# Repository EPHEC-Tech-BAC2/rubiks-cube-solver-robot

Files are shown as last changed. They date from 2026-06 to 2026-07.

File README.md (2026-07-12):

# Rubik's Cube Solver Robot

Projet réalisé à l'EPHEC-Tech (A2073 — Robotique Part 2, classe 2AU, 2025-2026), en équipe de trois : **EL YAZAMI Yassine**, **MAZID Mohamed**, **ELHAMAYDA Amer**.

## Le projet

Conception et réalisation d'un robot autonome capable de scanner, résoudre et exécuter physiquement la solution d'un Rubik's Cube, sans intervention humaine. Le système combine trois domaines : électronique, mécanique et développement logiciel.

Le robot scanne les 6 faces du cube via une caméra, calcule la solution optimale avec l'algorithme de Kociemba, puis l'exécute grâce à 4 bras motorisés pilotés par un Raspberry Pi Pico W.

## Partie électronique

PCB sur mesure conçu sous **EasyEDA** et fabriqué via **JLCPCB** (81,15 × 88,14 mm, 21 composants, 2 couches de cuivre, 141 pastilles traversantes, 6 vias).

| Composant | Référence | Rôle |
|---|---|---|
| Raspberry Pi Pico W | RP2040 | Microcontrôleur principal (firmware MicroPython) |
| Module Bluetooth | HC-05 | Communication sans fil PC ↔ Pico (UART, 38400 bauds) |
| Lecteur RFID | MFRC522 | Identification par badge, autorisation d'accès |
| Écran OLED | SSD1306 0,96" | Affichage état du robot, face scannée, progression |
| LED RGB | TJ-L5FCMXHTCSLCRGB | Indicateur visuel (rouge = bloqué, vert = prêt, bleu = actif) |
| Servomoteurs | MG90S x8 | 4 rotations + 4 pinces, PWM 50 Hz |
| Bouton | TS665CJ | Appui court = toggle pinces, appui long = scan auto |

L'alimentation des servomoteurs est séparée de celle du Pico pour éviter les chutes de tension lors des mouvements simultanés.

## Partie mécanique

Structure organisée autour d'une base centrale (découpée au laser) sur laquelle se fixent 4 bras en croix (Front, Back, Left, Right), chacun composé d'un servomoteur de rotation et d'un servomoteur de pince. Toutes les pièces ont été modélisées sous **Fusion 360** et imprimées en PLA :

- Platine principale (support servomoteur de rotation)
- Colonne verticale (support servomoteur de pince)
- Pince en U (saisie des faces du cube)
- Support de caméra
- Engrenage et cadre structural en U

Plusieurs itérations d'impression ont été nécessaires pour ajuster les tolérances dimensionnelles et obtenir des mouvements précis. Chaque bras dispose de son propre calibrage (ROT_CENTER, GRIP_HOLD) pour compenser les asymétries mécaniques.

## Partie programmation

Architecture logicielle en deux blocs communiquant en Bluetooth :

- **Firmware Pico (MicroPython)** : gestion des 8 servomoteurs, lecture RFID, affichage OLED, machine à états (IDLE/MOVING/SCAN)
- **Application PC (Python 3, Tkinter)** : capture caméra, détection des couleurs (OpenCV/HSV), interface graphique, résolution Kociemba

Protocole de communication maison : `START:TAG:PAYLOAD:END\n`, avec des tags dédiés (MOVE, GRAB/RELEASE, START_SCAN, PROG, DONE, AUTH...).

**Détection des couleurs** : analyse HSV par patch, vote majoritaire sur 7 captures par face pour plus de robustesse (l'orange est testé avant le rouge, leurs plages HSV étant adjacentes).

**Résolution** : algorithme de Kociemba embarqué localement (hors ligne), garantissant une solution en 20 mouvements maximum.

## Difficultés rencontrées

- Précision des angles de servomoteurs → calibrage individuel par bras
- Confusion orange/rouge en détection HSV → ordre de test + fallback par distance circulaire
- Instabilité de la détection couleur → vote majoritaire sur 7 captures
- Bruit d'initialisation du HC-05 → parsing basé sur la recherche du pattern `START:`
- Chutes de tension lors des mouvements simultanés → alimentation séparée + séquencement
- Tolérances d'impression 3D → révisions dimensionnelles successives

## Contenu du dépôt

- `Partie électronique/` : fichier PCB et export Gerber
- `Partie mécanique/` : fichiers STL de toutes les pièces imprimées + fichier DWG du support du robot
- `Partie programmation/` : firmware MicroPython (dossier `PICO/`) et application de contrôle (dossier `PC/`)
- `Présentation/` : support PowerPoint de la présentation finale
- `Rapport/` : rapport complet du projet (DOCX + PDF)

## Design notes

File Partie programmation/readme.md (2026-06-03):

# A2073 - Robotique part2 - 2025-2026
## Robot Solveur Rubik's Cube 3x3x3

**Groupe : B2**
- NOM Prénom (Matricule)
- EL YAZAMI Yassine (HE305212)
- ELHAMAYDA Amer (HE305196)
- MAZID Mohamed (HE305165)

**Objectifs :**  
Initialisation du projet et mise en place des bases logicielles et matérielles (Pico W, Bluetooth, librairies Python)  

**État actuel :**  
- Structure du projet créée 
- Librairies MicroPython (ssd1306, servo, mfrc522)  
- Dépendances Python ajoutées (numpy, opencv-python, pyserial, kociemba)  
- Début de la conception mécanique et du PCB  
- Test pour vérifier la communication Bluetooth entre le Pico et le PC avant l’intégration dans le projet
- Lancer l'interface et se connecter au Pico
- Les boutons Attraper/Relâcher envoient au Pico, le RFID s'affiche, le chrono tourne.
- Camera dans l'interface + cube mis a jour apres chaque capture
- Capturer 6 faces, resoudre, envoyer au pico, voir la progression en direct
- Utilisation de l'écran OLED pour afficher l’état et les messages du robot.
- Lecture de badges RFID pour l’identification.
- Mise en place de l’application Tkinter avec l’affichage du cube, la caméra live, le Bluetooth, le RFID, le chronomètre et le journal d’événements.
- Ajout du flux de capture des 6 faces du cube, la détection des couleurs, l’actualisation de l’état du cube à l’écran et la construction de la chaîne de résolution Kociemba.
- Passer le lancement par un écran d’accueil.
- Afficher le retour caméra directement dans l’interface.
- Construire la chaîne Kociemba après le scan complet.
- Calculer et afficher la solution du cube.
- Envoyer automatiquement les mouvements au robot.
- Mettre à jour l’état du cube pendant l’exécution des mouvements.
- Gérer la progression de la résolution en live.
- version finale de la communication BT, interface PC, OLED et RFID.

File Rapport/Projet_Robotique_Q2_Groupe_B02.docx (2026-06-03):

EPHEC — HAUTE ECOLE | TECH

Classe : 2AU — Année académique 2025-2026

A2073 - Robotique (Part 2)

RAPPORT FINAL

Rubik's Cube Solver Robot

Conception et réalisation d'un robot autonome de résolution du Rubik's Cube

Réalisé par :

EL YAZAMI Yassine

MAZID Mohamed

ELHAMAYDA Amer

Déposé le : mercredi 3 juin 2026

# Table des matières

# Introduction

Le Rubik’s Cube est un puzzle inventé en 1974 par l’architecte hongrois Ernő Rubik. Avec ses 43 quintillions de configurations possibles, ses 6 faces et ses 26 pièces mobiles, il représente un vrai défi, autant sur le plan mathématique qu’algorithmique. En 2010, des chercheurs ont montré que n’importe quelle position du cube peut être résolue en 20 mouvements maximum.

C’est dans ce contexte que s’inscrit notre projet de deuxième année dans le cadre du cours A2073 – Robotique. L’objectif était de concevoir et de réaliser un robot capable de résoudre automatiquement un Rubik’s Cube, sans intervention humaine, en combinant trois domaines complémentaires : la mécanique, l’électronique embarquée et le développement logiciel.

Le système final mis au point par notre équipe repose sur une architecture en deux parties. D’un côté, un Raspberry Pi Pico équipé d’un PCB conçu sur mesure pilote huit servomoteurs répartis en quatre bras, lit un badge RFID, affiche des informations sur un écran OLED et communique sans fil grâce à un module Bluetooth HC-05. De l’autre, une application Python exécutée sur PC s’occupe de capturer et d’analyser les couleurs du cube à l’aide d’une caméra, de calculer la solution avec l’algorithme Kociemba, puis de piloter l’ensemble du processus via une interface graphique Tkinter.

Ce rapport final présente tout le travail réalisé au cours de l’année académique 2025-2026. Il est organisé en trois grandes parties techniques — électronique, mécanique et programmation — chacune suivie d’une conclusion partielle. L’ensemble se termine par un bilan des difficultés rencontrées et une conclusion générale.

# 1. Partie électronique

## 1.1 Présentation des composants

L'ensemble de l'électronique du robot repose sur un PCB sur mesure, conçu avec le logiciel EasyEDA et fabriqué via JLCPCB. Ce PCB mesure 81,15 mm × 88,14 mm et intègre 21 composants répartis sur 2 couches de cuivre, avec 141 pastilles traversantes et 6 vias. Le tableau suivant détaille les composants utilisés.

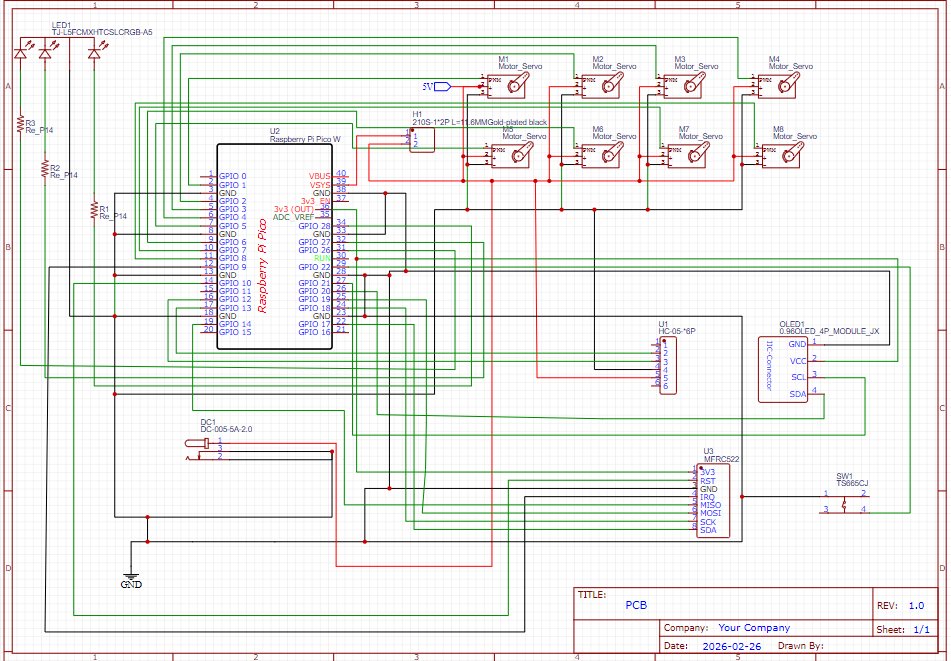
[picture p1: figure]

Figure 1 — Liste des composants générée depuis EasyEDA / JLCPCB

Composant | Référence | Rôle dans le système
Raspberry Pi Pico W | RP2040 | Microcontrôleur principal — firmware MicroPython
Module Bluetooth | HC-05 | Communication sans fil PC — PICO (UART, 38 400 bauds)
Lecteur RFID | MFRC522 | Identification par badge — autorisation d'accès
Ecran OLED | SSD1306 0,96" | Affichage état du robot, face scannée, progression
LED RGB | TJ-L5FCMXHTCSLCRGB | Indicateur visuel d'état (rouge = bloqué, vert = prêt, bleu = actif)
Servomoteurs | MG90S x8 | 4 rotations + 4 pinces — pilotés par PWM 50 Hz — 1,8 kg/cm à 5V
Bouton | TS665CJ | Appui court : toggle pinces — Appui long : scan auto
Connecteur alimentation | DC-005-5A-2.0 | Alimentation externe 5 V pour les servomoteurs
Résistances | Re_P14 x3 | Protection des lignes de signal GPIO

Tableau 1 — Composants électroniques du système

Le Raspberry Pi Pico W a été choisi pour ses nombreuses possibilités de connexion matérielle. Il dispose de deux cœurs ARM Cortex-M0+ à 133 MHz, de nombreux GPIO pouvant être utilisés en PWM, de deux ports UART, ainsi que des bus I2C et SPI. Son support de MicroPython facilite le développement et les tests du firmware.

L’alimentation des servomoteurs est séparée de celle du Pico afin d’éviter les baisses de tension qui peuvent apparaître lorsque plusieurs moteurs fonctionnent en même temps.

## 1.2 Schéma électrique

Le schéma électrique ci-dessous a été réalisé sous EasyEDA. Il représente l'ensemble des connexions entre le Raspberry Pi Pico W et les composants périphériques : les huit servomoteurs (M1 à M8), le module Bluetooth HC-05 (U1), l'écran OLED (via connecteur I2C), le lecteur RFID MFRC522 (U3), la LED RGB (LED1), le bouton (SW1) et le connecteur d'alimentation DC (DC1).

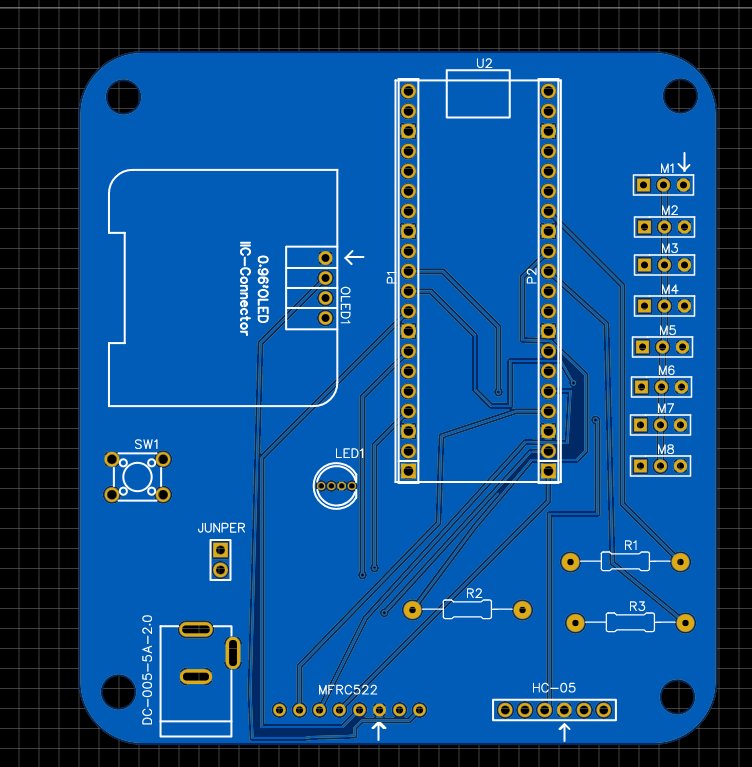
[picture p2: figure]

Figure 2 — Schéma électrique complet du PCB (EasyEDA, révision 1.0 — 26/02/2026)

Les interfaces de communication utilisées sont les suivantes :

- UART 0 (GPIO 12 TX / GPIO 13 RX, buffer 512 octets) : communication Bluetooth avec le HC-05 à 38 400 bauds
- SPI 0 (GPIO 18 SCK / GPIO 19 MOSI / GPIO 0 MISO / GPIO 17 CS / GPIO 10 RST) : lecteur RFID MFRC522
- I2C 0 (GPIO 20 SDA / GPIO 21 SCL) : écran OLED SSD1306 128x64 pixels
- PWM sur GPIO 1-8 : pilotage des 8 servomoteurs (fréquence 50 Hz)
- PWM sur GPIO 26, 27, 2 : LED RGB (rouge, vert, bleu)
- GPIO 22 (entrée pull-up) : bouton physique

## 1.3 Conception et routage du PCB

Le routage du PCB a été réalisé sous EasyEDA en tenant compte de la place disponible et de l’organisation des différents composants. Les connecteurs des huit servomoteurs (M1 à M8) ont été regroupés sur le côté droit de la carte afin de faciliter le câblage vers les bras du robot. Le module HC-05 et le lecteur MFRC522 sont placés dans la partie inférieure du PCB pour rendre leurs connexions plus accessibles. Les résistances de protection R1, R2 et R3 ont été installées au plus près des GPIO concernés.

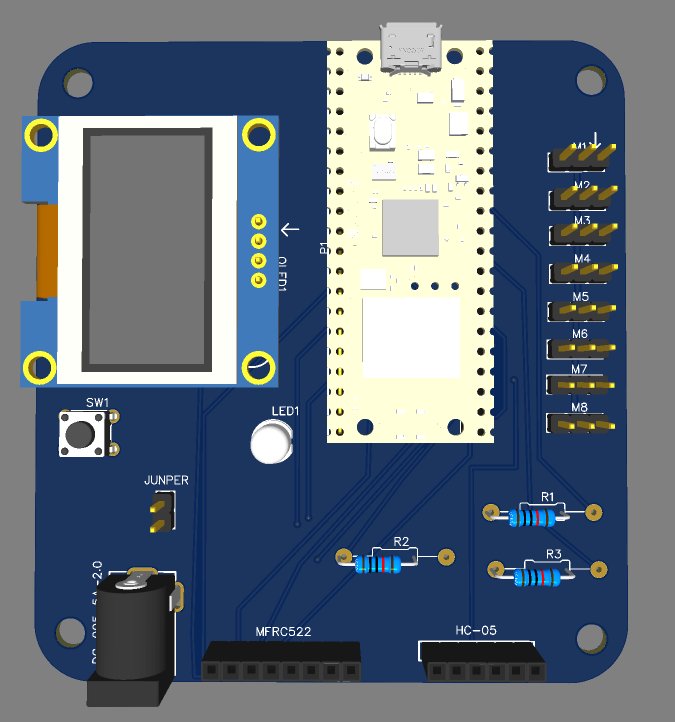
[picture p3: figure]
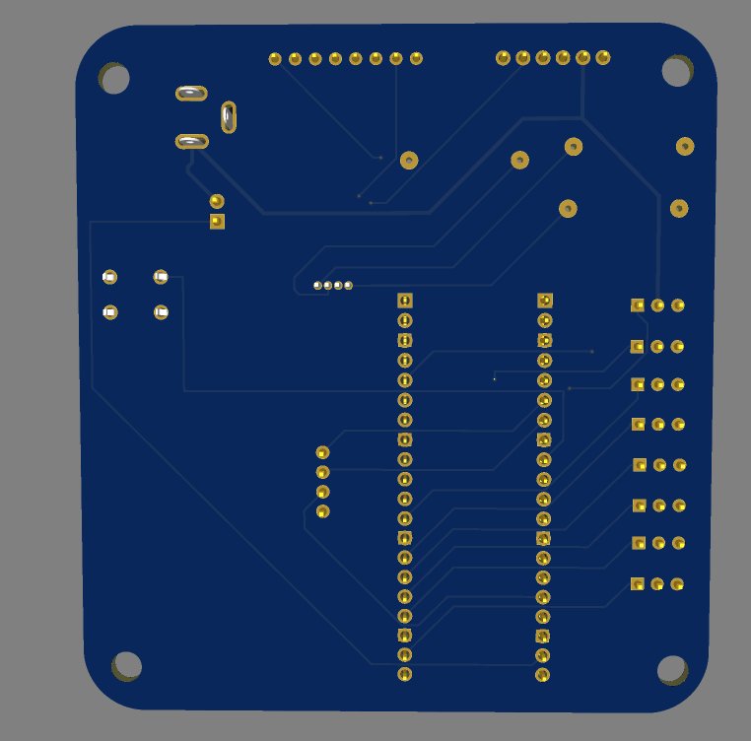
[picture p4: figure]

Figure 3 — Vue de routage du PCB (gauche) et rendu 3D vue de dessus avec composants (droite)

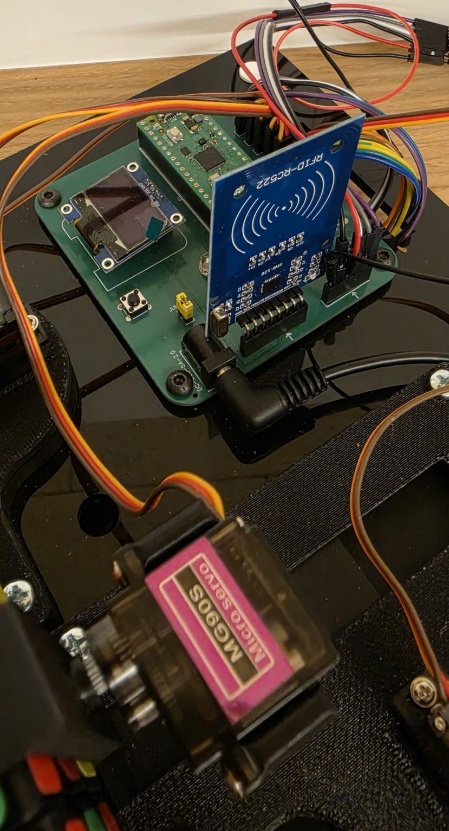
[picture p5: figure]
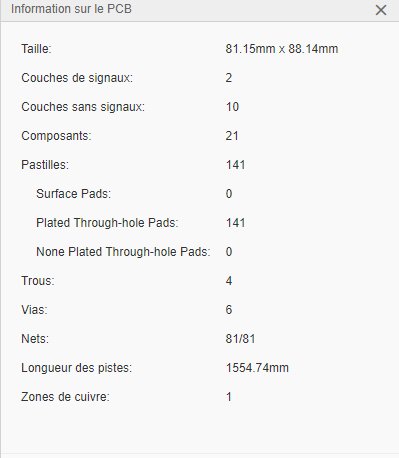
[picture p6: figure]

Figure 5 — PCB physique après soudure et assemblage

Conclusion partielle — Partie électronique

La partie électronique du projet a abouti à la conception et à la fabrication d'un PCB sur mesure de 81,15 mm × 88,14 mm, intégrant 21 composants sur 2 couches. Le Raspberry Pi Pico W centralise l'ensemble des interfaces matérielles nécessaires au projet : PWM pour les servomoteurs, UART pour le Bluetooth, SPI pour le RFID et I2C pour l'OLED. La séparation de l'alimentation des servomoteurs et du microcontrôleur garantit la stabilité du système lors des mouvements. Les tests unitaires réalisés composant par composant ont validé le bon fonctionnement de chaque module avant l'intégration finale.

# 2. Partie mécanique

## 2.1 Structure générale

La structure mécanique du robot est organisée autour d'une base centrale sur laquelle viennent se fixer quatre bras disposés en croix, chacun orienté vers l'une des quatre faces latérales du cube (Front, Back, Left, Right). Chaque bras est composé d'un servomoteur de rotation et d'un servomoteur de pince, ce qui permet de saisir et de faire tourner le cube selon les axes nécessaires à la résolution. La conception de toutes les pièces a été réalisée avec le logiciel Fusion 360.

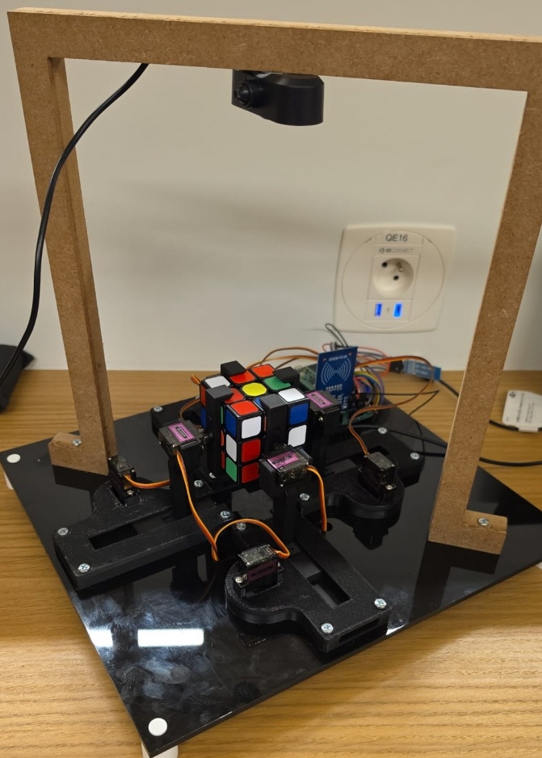
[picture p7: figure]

Figure 6

## 2.2 Base découpée au laser

La base du robot est une plaque découpée au laser portant l'inscription « Rubik's Cube Solveur — Robotique A2073 — 2025/2026 ». Elle comporte quatre emplacements symétriques destinés à recevoir les bras du robot, avec des encoches de fixation permettant un positionnement précis. Des trous de fixation aux quatre coins permettent de stabiliser l'ensemble sur la surface de travail.

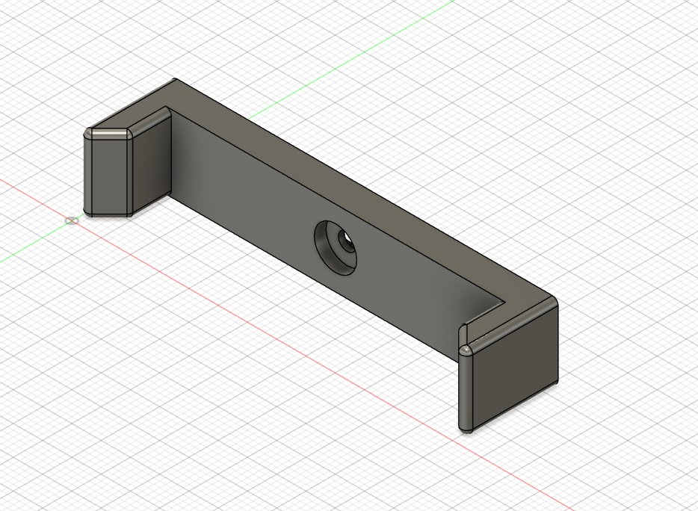
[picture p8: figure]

Figure 7 — Plan de découpe laser de la base du robot (fusion / vue CAO)

## 2.3 Pièces modélisées en 3D sur Fusion 360

L'ensemble des pièces constitutives des bras a été modélisé en 3D sous Fusion 360 et imprimé en PLA. Chaque bras est un assemblage de plusieurs pièces distinctes, dont les rôles sont décrits ci-dessous. Plusieurs itérations d'impression ont été nécessaires afin d'ajuster les tolérances dimensionnelles et d'obtenir des mouvements précis et sans jeu excessif.

### Support de servomoteur — platine principale

La platine principale constitue la base de chaque bras. Elle accueille le servomoteur de rotation et assure la fixation sur la base laser. Sa forme intègre les dégagements nécessaires à l'axe du servomoteur et les trous de fixation permettant un montage rigide.

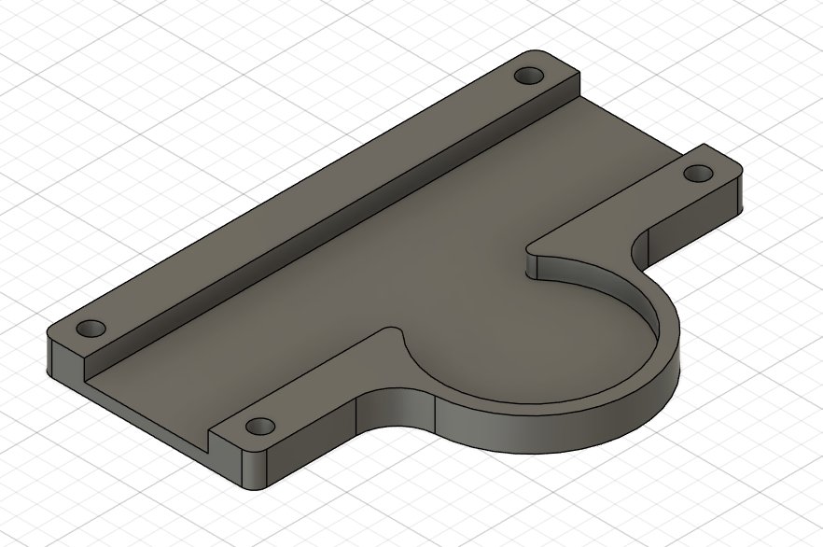
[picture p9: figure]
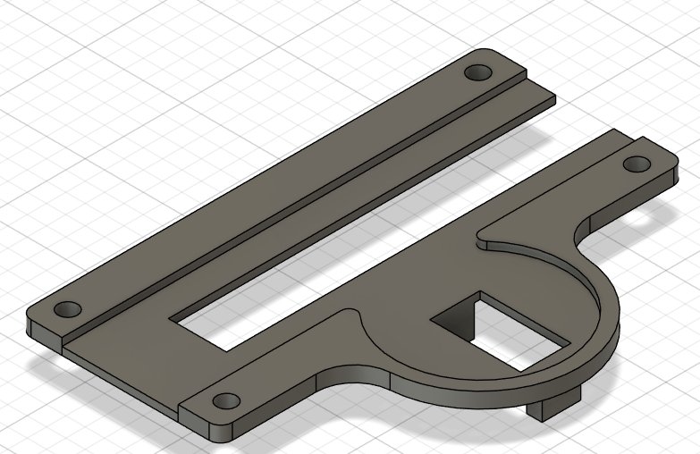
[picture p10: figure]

Figure 8 — Platine support du servomoteur de rotation : version pleine (gauche) et avec dégagement axe (droite)

### Support vertical — colonne de bras

La colonne verticale supporte le servomoteur de pince à la hauteur du cube. Elle est fixée sur la platine principale et maintient le servomoteur de pince en position haute, de manière à ce que la pince soit alignée avec les faces du cube positionné au centre du robot.

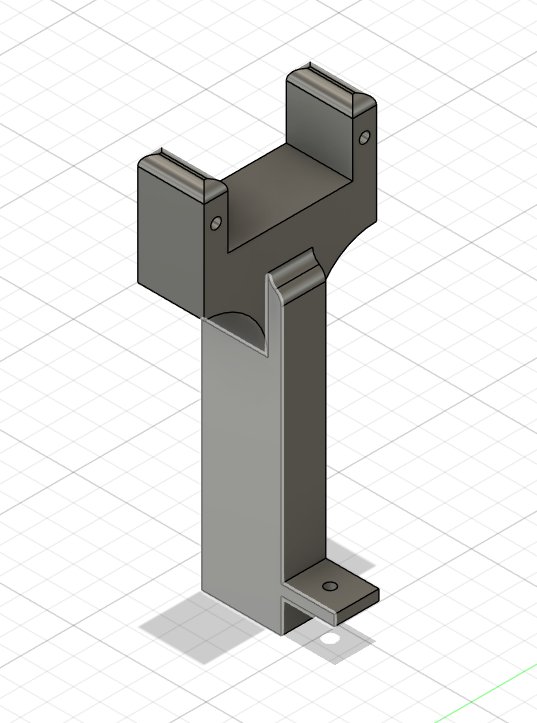
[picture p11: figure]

Figure 9 — Colonne verticale du bras avec support de pince

### Pince — bras de saisie

La pince est l'élément qui entre directement en contact avec le cube. Elle est actionnée par le servomoteur de pince et alterne entre deux positions : serrée (saisie du cube) et ouverte (relâche). Sa forme en U permet d'envelopper une face du cube sans glisser lors des rotations.

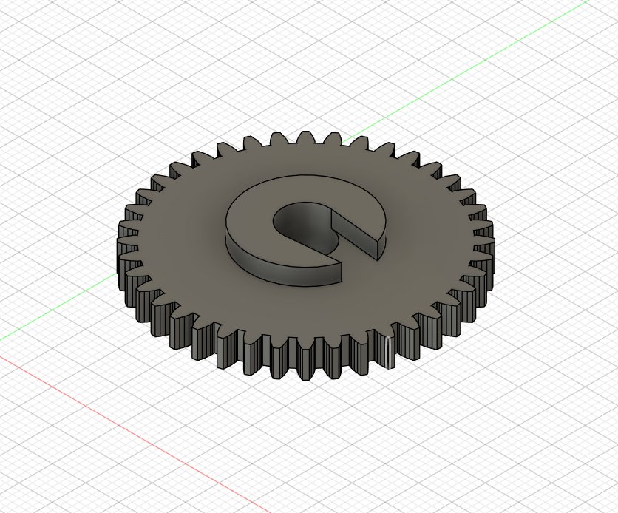
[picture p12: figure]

Figure 10 — Pièce de pince en U — saisie des faces du cube

### Support de caméra

Le support de caméra est la pièce qui maintient la caméra USB en position fixe au-dessus du centre du robot. Sa forme rectangulaire avec encoches latérales permet un positionnement stable et ajustable en hauteur. La lumière centrale guide le câble de la caméra et l'orifice de fixation assure un maintien rigide pendant les mouvements du robot.

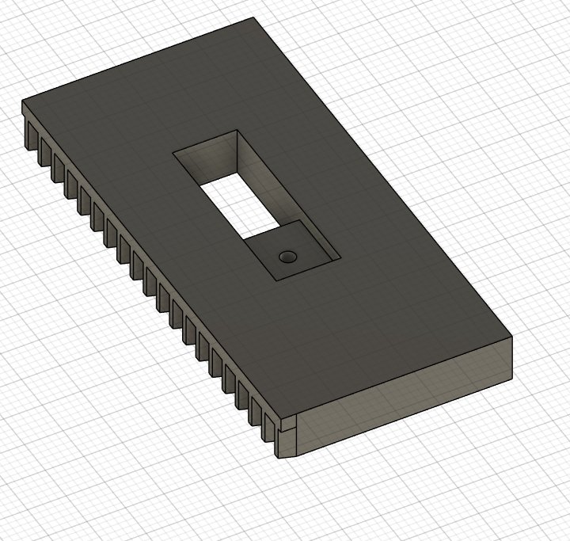
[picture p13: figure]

Figure 11 — Support de caméra (modélisation Fusion 360)

### Engrenage

Un engrenage a été modélisé pour assurer la transmission de mouvement dans les configurations nécessitant un rapport de démultiplication ou un changement d'axe. Le trou central en D garantit l'enclenchement sur l'axe du servomoteur.

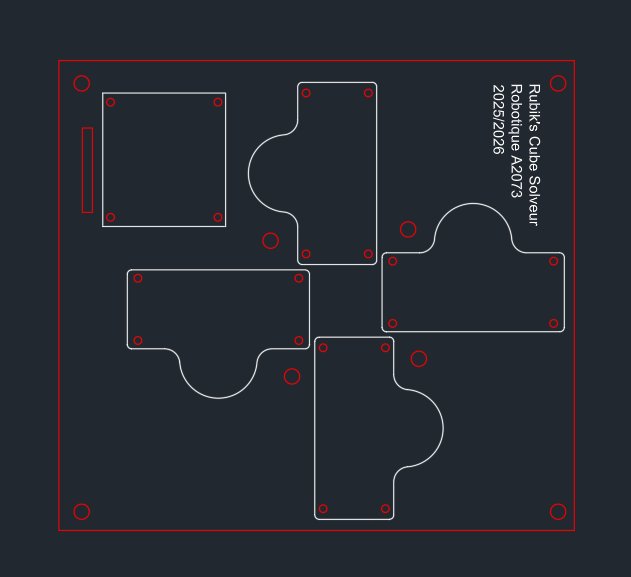
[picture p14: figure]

Figure 12 — Engrenage avec trou en D pour axe servomoteur

### Cadre de structure

Le cadre en U constitue l'ossature externe de chaque bras. Il relie la platine principale à la colonne verticale et offre un support rigide à l'ensemble du mécanisme. Ses dimensions ont été ajustées pour s'adapter à la taille standard d'un Rubik's Cube 3x3.

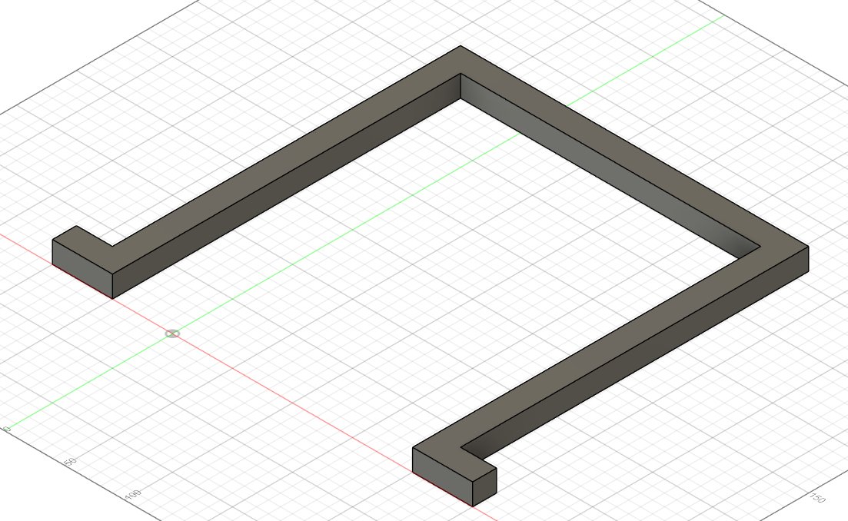
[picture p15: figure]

Figure 13 — Cadre structural en U du bras

Caractéristique | Valeur (4,8V) | Valeur (6V)
Poids | 13,4 g | —
Dimensions | 22,5 × 12 × 35,5 mm | —
Couple de blocage | 1,8 kg/cm | 2,2 kg/cm
Vitesse de rotation (60°) | 0,10 s | 0,08 s
Tension de fonctionnement | 4,8 V — 6,6 V | —
Signal PWM | 50 Hz — impulsion 1 à 2 ms | —
Type d'engrenages | Métal | —

Tableau 2 — Caractéristiques techniques du servomoteur MG90S

Paramètre | Bras L | Bras R / F | Bras B
ROT_CENTER (position neutre) | 86° | 90° | 94°
GRIP_HOLD (saisie) | 20° | 18° / 30° | 35°
GRIP_OPEN (relâche) | 100° | 100° | 100°
TEMPS_MVT (résolution) | 0,12 s | 0,12 s | 0,12 s
TEMPS_SCAN (scan faces) | 0,30 s | 0,30 s | 0,30 s

Tableau 3 — Paramètres de calibrage par bras (version finale)

Conclusion partielle — Partie mécanique

La conception mécanique a été l'aspect le plus itératif du projet. La découpe laser a fourni une base précise et reproductible, tandis que la modélisation Fusion 360 a permis de concevoir et d'ajuster les pièces des bras avant chaque impression. Plusieurs révisions ont été nécessaires pour corriger les tolérances et obtenir des mouvements fiables. La calibration individuelle de chaque bras (ROT_CENTER différent pour L, R, F et B) a permis de compenser les légères asymétries mécaniques et d'obtenir une précision de positionnement satisfaisante.

# 3. Partie programmation

## 3.1 Architecture logicielle globale

Le système logiciel est divisé en deux blocs indépendants qui coopèrent via une liaison Bluetooth : le firmware embarqué sur le Raspberry Pi Pico, développé en MicroPython, et l'application de contrôle tournant sur PC, développée en Python 3 avec l'environnement de développement VS Code.

Les deux parties communiquent via un protocole maison structuré sous la forme :

START : TAG : PAYLOAD : END\n

Ce format permet d'identifier chaque type de message et de le distinguer facilement du bruit ou des messages d'initialisation émis spontanément par le module HC-05. Un buffer logiciel côté Pico (rxbuf=512 octets) absorbe les longues solutions Kociemba sans perte de données.

L'algorithmme ci-dessous présente le fonctionnement général du système, côté PC (gauche) et côté Raspberry Pi Pico (droite). Il illustre les deux flux parallèles et leurs points de synchronisation via Bluetooth.

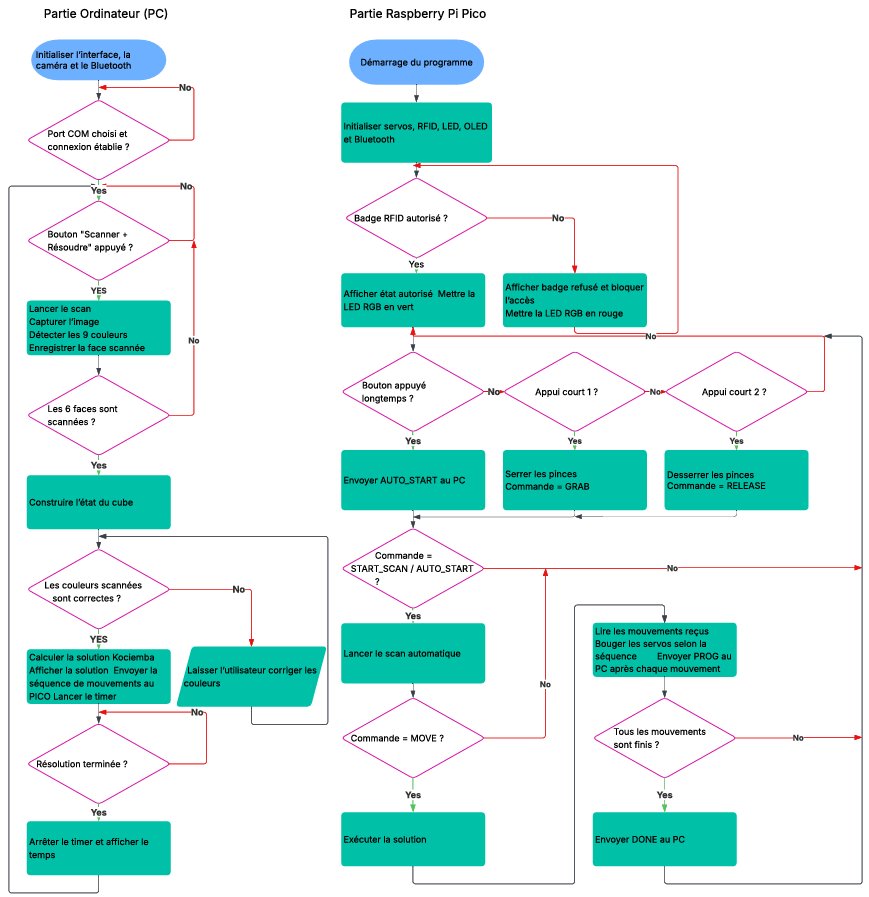
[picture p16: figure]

Figure 14 — Algorithmme général du système — Partie PC (gauche) et Partie PICO (droite)

Direction | Tag | Description
PC -> PICO | MOVE | Séquence de mouvements à exécuter (ex: R U R' F2)
PC -> PICO | GRAB / RELEASE | Serrer ou relâcher les 4 pinces
PC -> PICO | START_SCAN | Déclencher le scan automatique des 6 faces
PC -> PICO | SCAN_ACK:face | Acquittement : face capturée avec succès
PICO -> PC | SCAN_READY:face | Face positionnée devant la caméra
PICO -> PC | SCAN_DONE:OK | Toutes les 6 faces ont été scannées
PICO -> PC | PROG:i/total | Progression : i-ème mouvement sur total
PICO -> PC | DONE:MOVE | Exécution de la séquence terminée
PICO -> PC | AUTH:id,0|1 | Résultat de lecture RFID (0=refusé, 1=autorisé)

Tableau 3 — Messages du protocole Bluetooth START:TAG:PAYLOAD:END

## 3.2 Firmware Raspberry Pi Pico (MicroPython)

### 3.2.1 Organisation des modules

Le firmware est organisé en huit modules distincts, chacun responsable d'une fonctionnalité précise, ce qui facilite la maintenance et les tests individuels.

Module | Auteur | Rôle
main.py | Amer | Boucle principale : RFID, bouton, Bluetooth, séquences
servo_controller.py | Amer | Gestion des 4 bras (8 servos) avec calibrage individuel par bras
servo.py | Amer | Classe bas niveau PWM 50 Hz — conversion angle vers duty cycle
state.py | Amer | Machine à états : IDLE, MOVING, SCAN
led_controller.py | Amer | LED RGB par PWM (pins 26, 27, 2) — indication visuelle état
bluetooth.py | Yassine | UART 0 (TX:12, RX:13) — buffer logiciel, parsing START:TAG:PLD:END
rfid_reader.py | Yassine | MFRC522 via SPI 0 — lecture badge, liste blanche, acquittement
oled_display.py | Yassine | SSD1306 via I2C 0 (SDA:20, SCL:21) — 4 lignes de 16 caractères

Tableau 4 — Modules du firmware PICO avec auteur

### 3.2.2 Boucle principale et gestion du bouton

La boucle principale du fichier main.py gère trois flux en simultané : la scrutation RFID toutes les 500 ms, la lecture du bouton physique et la réception de commandes Bluetooth. Le bouton dispose de deux comportements selon la durée d'appui :

- Appui court (< 800 ms) : bascule l'état des pinces entre ouvert et serré, permettant de positionner manuellement le cube
- Appui long (> 800 ms) : déclenche la séquence de scan automatique auto_scan(), à condition que le badge RFID ait été préalablement validé

Le système RFID utilise une liste blanche (ALLOWED_TAGS = [54206395]). Si le badge présenté n'est pas autorisé, toutes les commandes sensibles sont bloquées et un message d'erreur est envoyé au PC (tag ERR:NOT_AUTHORIZED). La LED rouge s'allume et l'OLED affiche un message de refus.

### 3.2.3 Contrôle des servomoteurs — calibrage individuel

La classe RobotController gère les quatre bras (F, B, L, R), chacun instancié comme un objet Bras avec ses propres constantes de calibrage. Cette approche par dictionnaire permet de compenser les légères différences mécaniques entre les bras sans modifier la logique de contrôle.

Chaque mouvement du Rubik's Cube (R, U', F2...) est traduit par la fonction executer_mouvement_rubiks() en une séquence d'appels servo : rotation CW ou CCW, relâche pince, retour centre, saisie. Les mouvements U et D, qui n'ont pas de bras dédié, sont réalisés par une combinaison de basculements du cube suivis d'une rotation de la face accessible. La résolution utilise TEMPS_MVT = 0,12 s par étape, tandis que le scan utilise TEMPS_SCAN = 0,30 s pour plus de stabilité.

### 3.2.4 Scan automatique des 6 faces

La fonction auto_scan() orchestre l'exposition de chacune des 6 faces du cube devant la caméra selon une séquence précise de basculements. Pour chaque face, le Pico envoie SCAN_READY:face et attend un acquittement SCAN_ACK:face du PC dans un délai maximal de 60 secondes. La LED passe en bleu pendant toute la durée du scan et l'OLED affiche la progression (Scan 1/6, Scan 2/6...).

## 3.3 Application PC (Python 3)

### 3.3.1 Interface graphique Tkinter

L'application PC est développée par Yassine et propose une interface graphique sombre (thème dark navy, BG=#1a1a2e) organisée en plusieurs zones : barre de connexion Bluetooth (port COM, baudrate), contrôles principaux (scan, résolution, envoi), flux caméra en temps réel, vue en croix des 6 faces du cube, panneau solution Kociemba et chronomètre. L'interface est responsive avec une taille minimale de 1200×720 pixels.

### 3.3.2 Détection des couleurs par caméra (OpenCV/HSV)

La détection des couleurs, développée par Mohamed, est réalisée en espace HSV via OpenCV. Pour chaque case du cube, un patch de 17×17 pixels est analysé et la couleur médiane est comparée à des plages HSV prédéfinies. L'ordre de vérification est crucial : l'orange est testé avant le rouge car leurs plages HSV sont adjacentes.

Couleur | H min | H max | Conditions supplémentaires
Blanc | 0 | 180 | S < 60 et V > 170
Orange | 6 | 22 | S > 100 et V > 80 — testé avant le rouge
Jaune | 23 | 38 | S > 80 et V > 80
Vert | 39 | 85 | S > 70 et V > 50
Bleu | 95 | 135 | S > 70 et V > 50
Rouge | 0-5 / 170-179 | — | S > 90 et V > 50 — double plage HSV circulaire

Tableau 5 — Plages de détection HSV par couleur (orange testé avant rouge)

Pour valider une face, la fonction snapshot_face() prend 7 captures successives et applique un vote majoritaire case par case : chaque case reçoit la couleur qui a obtenu le plus de votes sur les 7 échantillons. Ce mécanisme rend la détection robuste aux variations d'éclairage ponctuelles. Si une case reste indéterminée sur tous les échantillons, la face est rejetée.

### 3.3.3 Visualisation du cube — CubeView

Le widget CubeView, développé par Mohamed, est un canvas Tkinter qui affiche les 6 faces du cube en disposition en croix (U en haut, L-F-R-B au centre, D en bas). Chaque case est cliquable, ce qui permet de corriger manuellement une couleur mal détectée par un cycle entre les 6 couleurs possibles. Le widget se met à jour en temps réel pendant la résolution simulée.

## 3.4 Algorithme de résolution — Kociemba

La résolution est assurée par l'algorithme de Herbert Kociemba, intégré localement via le dossier twophase/ qui contient les tables de recherche précalculées. L'algorithme fonctionne donc hors ligne, sans dépendance à un service externe.

Une fois les 6 faces scannées, la fonction build_kociemba_string() construit une chaîne de 54 caractères : elle identifie chaque couleur à la face dont le centre porte cette couleur, puis concatène les 54 cases dans l'ordre U-R-F-D-L-B. La bibliothèque kociemba.solve() retourne la séquence optimale en notation standard (R, U', F2...).

# Construction de la chaîne + résolution cube_string = build_kociemba_string(faces) # ex: 'UUUUUUUUURRRRRR...' solution = kociemba.solve(cube_string) # ex: "R U R' F2 L D ..."

La solution est ensuite transmise au Pico via Bluetooth (MOVE:R U R' F2...). Le Pico exécute chaque mouvement séquentiellement et renvoie PROG:i/total après chaque étape. L'interface PC met à jour la barre de progression et simule simultanément la résolution sur le CubeView grâce au module CubeState.

Conclusion partielle — Partie programmation

L'architecture logicielle modulaire adoptée, avec une séparation nette entre le firmware PICO et l'application PC, a permis un développement en parallèle efficace entre les membres de l'équipe. Le protocole Bluetooth START:TAG:PAYLOAD:END s'est révélé robuste et simple à implémenter des deux côtés, avec une gestion propre du bruit d'initialisation du HC-05. La détection couleur par vote majoritaire sur 7 captures offre une fiabilité supérieure aux approches à seuil fixe. L'algorithme Kociemba embarqué localement garantit une résolution optimale en 20 mouvements maximum, pour un temps d'exécution physique de l'ordre de 20 secondes avec TEMPS_MVT = 0,12 s.

# 4. Difficultés rencontrées

La réalisation de ce projet a mis en lumière plusieurs défis techniques, organisationnels et pratiques que notre équipe a dû identifier et surmonter au fil des semaines de développement.

Difficulté | Solution apportée | Résultat
Précision des angles de servomoteurs : certains bras manquaient leur position cible, provoquant des blocages mécaniques | Calibrage individuel par bras via les dictionnaires ROT_CENTER, GRIP_HOLD — chaque bras possède ses propres constantes | Résolu — mouvements reproductibles
Confusion orange/rouge lors de la détection HSV, particulièrement sous éclairage artificiel variable | L'orange est vérifié avant le rouge dans la fonction detect_color(). Ajout d'un fallback par distance circulaire sur la teinte H | Résolu
Instabilité de la détection couleur : résultats différents d'une capture à l'autre pour la même face | Remplacement du système de seuil par un vote majoritaire sur 7 captures (snapshot_face) — plus robuste aux variations ponctuelles | Résolu
Bruit d'initialisation du HC-05 : messages parasites ('OK\r\n') corrompaient le parsing du protocole | Buffer logiciel côté PICO : le code cherche le pattern START: dans le flux et ignore tout ce qui précède. rxbuf=512 pour les longues solutions | Résolu
Chutes de tension lors des mouvements simultanés de plusieurs servomoteurs | Alimentation séparée des servomoteurs (DC-005-5A-2.0). Séquencement des mouvements avec délais pour lisser les pics de courant | Résolu
Tolérances d'impression 3D : encoches trop serrées ou trop lâches pour les servomoteurs | Révisions des fichiers Fusion 360 avec ajustement dimensionnel (+0,2 mm sur les encoches) et réimpression des pièces concernées | Résolu

Tableau 6 — Difficultés rencontrées et solutions mises en place

Au-delà des aspects techniques, la coordination entre les trois membres de l'équipe sur des domaines différents (mécanique, électronique, programmation) a nécessité une organisation rigoureuse. Les dépendances entre les parties — notamment entre le firmware PICO et l'application PC — ont imposé de définir clairement les interfaces (protocole Bluetooth, format des messages) avant de commencer le développement, afin que chaque membre puisse travailler indépendamment.

# 5. Conclusion générale

Ce projet de robotique constitue l'aboutissement d'une année de travail pluridisciplinaire. L'objectif initial — concevoir et réaliser un robot capable de scanner, résoudre et exécuter la solution d'un Rubik's Cube de manière entièrement autonome — a été atteint.

Sur le plan électronique, le PCB conçu sous EasyEDA et fabriqué via JLCPCB offre une intégration compacte et fiable de l'ensemble des composants. Le Raspberry Pi Pico W s'est révélé être un choix pertinent grâce à la diversité de ses interfaces et à la facilité de développement offerte par MicroPython.

Sur le plan mécanique, la structure en croix avec base laser et bras imprimés en PLA offre un positionnement précis du cube. Le calibrage individuel par bras, rendu possible par l'utilisation de dictionnaires de constantes dans le firmware, a permis de compenser les asymétries mécaniques inévitables dans un système d'impression 3D.

Sur le plan logiciel, l'architecture modulaire avec séparation PC/PICO et protocole Bluetooth bien défini a facilité le travail en équipe. La détection couleur par vote majoritaire et la résolution via l'algorithme Kociemba embarqué localement forment un pipeline robuste, capable de résoudre un cube mélangé en une vingtaine de secondes.

Ce projet nous a apporté de nombreux enseignements. Nous avons appris à travailler sur un système pluridisciplinaire où chaque partie dépend des autres, à gérer les contraintes du monde physique (tolérances mécaniques, variations d'éclairage, bruit électronique), et à nous organiser efficacement en équipe sur plusieurs mois.

En termes de perspectives d'amélioration, plusieurs pistes sont envisageables : l'utilisation de servomoteurs à retour de position pour une meilleure précision, l'intégration d'un éclairage contrôlé autour de la caméra pour une détection couleur plus stable, ou encore l'utilisation d'un modèle de vision par apprentissage automatique pour remplacer la détection HSV.

# 6. Bibliographie

## Documentation technique des composants

[1] Raspberry Pi Foundation. Raspberry Pi Pico Datasheet — RP2040 microcontroller. Disponible sur : https://datasheets.raspberrypi.com/pico/pico-datasheet.pdf
[2] NXP Semiconductors. MFRC522 — Standard performance MIFARE and NTAG frontend, Datasheet Rev. 3.9. 2016.
[3] Solomon Systech. SSD1306 — 128x64 Dot Matrix OLED/PLED Segment/Common Driver with Controller. 2008.
[4] TOGIALE. TJ-L5FCMXHTCSLCRGB-A5 — RGB LED Through-Hole Component. Fiche produit LCSC référence C2837020.
[5] SHOU HA. TS665CJ — Tactile Push Button Switch. Fiche produit LCSC référence C393938.
[6] HC-05 Bluetooth Serial Module — AT Commands Reference and Datasheet. Document technique fabricant.

## Logiciels et outils de développement

[7] EasyEDA — Logiciel de conception de schémas et PCB en ligne. JLCPCB. Disponible sur : https://easyeda.com/
[8] Autodesk Fusion 360 — Logiciel de modélisation 3D paramétrique. Disponible sur : https://www.autodesk.com/products/fusion-360/
[9] Visual Studio Code — Editeur de code source. Microsoft. Disponible sur : https://code.visualstudio.com/
[10] MicroPico — Extension VS Code pour le développement MicroPython sur Raspberry Pi Pico. Disponible sur : https://marketplace.visualstudio.com/items?itemName=paulober.pico-w-go

## Bibliothèques logicielles

[11] Python Software Foundation. Python 3.13 Documentation. Disponible sur : https://docs.python.org/3/
[12] MicroPython. MicroPython Documentation for RP2040. Disponible sur : https://docs.micropython.org/
[13] OpenCV Team. OpenCV 4.x Documentation. Disponible sur : https://docs.opencv.org/
[14] PyPI. pyserial 3.5 — Python Serial Port Extension. Disponible sur : https://pypi.org/project/pyserial/
[15] PyPI. kociemba 1.2.1 — Python wrapper for Herbert Kociemba's two-phase algorithm. Disponible sur : https://pypi.org/project/kociemba/
[16] PyPI. numpy — Fundamental package for scientific computing with Python. Disponible sur : https://numpy.org/
[17] Python Standard Library. tkinter — Python Interface to Tcl/Tk. Disponible sur : https://docs.python.org/3/library/tkinter.html
[18] PyPI. Pillow 10.x — Python Imaging Library (PIL Fork). Disponible sur : https://pypi.org/project/pillow/

## Algorithme de résolution

[19] Kociemba, H. Two-Phase Algorithm for solving Rubik's Cube. Documentation officielle. Disponible sur : http://kociemba.org/cube.htm
[20] Rokicki, T., Kociemba, H., Davidson, M., Dethridge, J. God's Number is 20. 2010. Disponible sur : https://www.cube20.org/
[21] Rui Santos & Sara Santos. Raspberry Pi Pico Servo Motor with MicroPython. Random Nerd Tutorials. Disponible sur : https://randomnerdtutorials.com/raspberry-pi-pico-servo-motor-micropython/

# 7. Annexes

## Annexe A — Liste complète des composants

Composant | Référence LCSC | Qté | Rôle
Raspberry Pi Pico W | — | 1 | Microcontrôleur principal
Module Bluetooth HC-05 | C40877 | 1 | Communication PC-PICO
Lecteur RFID MFRC522 | C27438 | 1 | Identification badge
Ecran OLED SSD1306 0,96" | C2718488 | 1 | Affichage état robot
LED RGB TJ-L5FCMXHTCSLCRGB | C2837020 | 1 | Indicateur visuel d'état
Servomoteur MG90S | C124376 | 8 | 4 rotations + 4 pinces (22,5×12×35,5mm, 13,4g, 1,8 kg/cm)
Bouton TS665CJ | C393938 | 1 | Contrôle physique
Connecteur DC-005-5A-2.0 | C381116 | 1 | Alimentation servomoteurs 5V
Résistances Re_P14 | — | 3 | Protection GPIO
Caméra USB | — | 1 | Détection couleurs des faces
PCB sur mesure (EasyEDA) | 81,15x88,14mm | 1 | Support de tous les composants
Base laser | — | 1 | Structure principale du robot
Pièces imprimées PLA | — | INSERER NB | Bras, pinces, coupleurs, engrenages

Tableau A1 — Liste complète des composants avec références LCSC

## Annexe B — Répartition des tâches

Membre | Fichiers et tâches réalisés
EL YAZAMI Yassine | PC/bluetooth/bt_uart.py — PC/ui/interface.py — PICO/bluetooth.py — PICO/oled_display.py — PICO/rfid_reader.py Interface graphique Tkinter, communication Bluetooth PC et PICO, affichage OLED, gestion RFID
MAZID Mohamed | PC/graphique/cube_view.py — PC/vision/color_detection.py — PC/solver/cube_solver.py — PC/vision/camera.py Détection couleur HSV, widget CubeView, résolution Kociemba, pipeline caméra
ELHAMAYDA Amer | PICO/main.py — PICO/servo_controller.py — PICO/servo.py — PICO/led_controller.py — PICO/state.py Firmware principal PICO, contrôle servomoteurs, calibrage, LED, machine à états

Tableau B1 — Répartition des tâches par membre de l'équipe

## Annexe C — Diagramme de Gantt

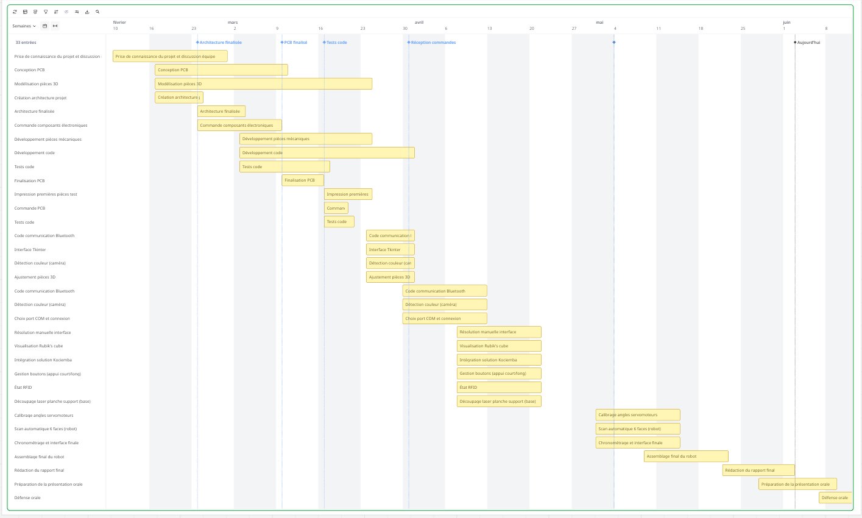
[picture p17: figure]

Figure C1 — Diagramme de Gantt complet du projet (février — juin 2026)

## Annexe D — Informations PCB

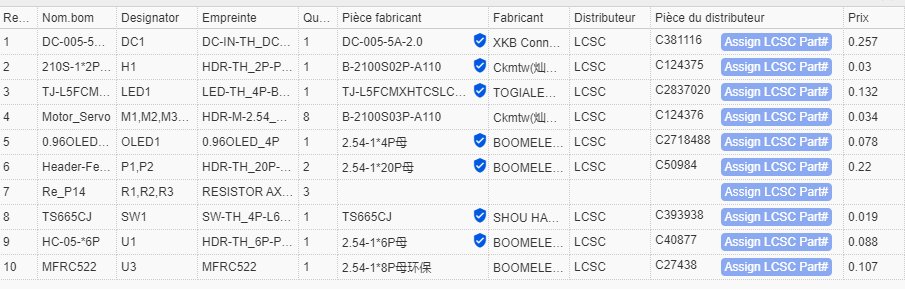
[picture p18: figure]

Figure D1 — Caractéristiques techniques du PCB (EasyEDA)

## Annexe E — Démonstration vidéo

Une vidéo de démonstration a été réalisée. Elle présente la résolution automatique complète du Rubik's Cube par le robot, de la reconnaissance du badge RFID jusqu'à la résolution finale par les servomoteurs.

Lien vers la vidéo de démonstration : Vidéo — Résolution automatique du Rubik's Cube par les servomoteurs (https://ephec-my.sharepoint.com/:v:/g/personal/he305212_students_ephec_be/IQAKoIiLbWsoRJQqvP-2FXlHAcKIOU5TgDkH55IeYEZhew8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)

EL YAZAMI Yassine — MAZID Mohamed — ELHAMAYDA Amer Page 1 / 2

A2073 — Robotique (Part 2) | Rapport Final | Rubik's Cube Solver — Groupe B02 EPHEC 2025-2026

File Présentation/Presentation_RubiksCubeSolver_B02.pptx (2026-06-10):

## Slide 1

A2073 — ROBOTIQUE (PART 2) · EPHEC 2025-2026

Rubik's Cube
Solver Robot

Conception et réalisation d'un robot autonome
de résolution du Rubik's Cube 3×3

EL YAZAMI Yassine MAZID Mohamed ELHAMAYDA Amer

Groupe B02 — Classe 2AU — Juin 2026

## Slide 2

INTRODUCTION

Un défi mécanique, électronique et logiciel

43×10¹⁸

configurations possibles

Objectif du projet

- Concevoir un robot qui scanne, calcule et exécute la solution d'un Rubik's Cube sans intervention humaine
- Combiner trois domaines : mécanique (4 bras), électronique embarquée (PCB sur mesure) et logiciel (PC + Pico)
- Identification par badge RFID, supervision par interface PC et communication Bluetooth

21

mouvements max.

Rubik's Cube Solver — Groupe B02

~20 s

temps de résolution de notre robot

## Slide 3

VUE D'ENSEMBLE

Architecture du système

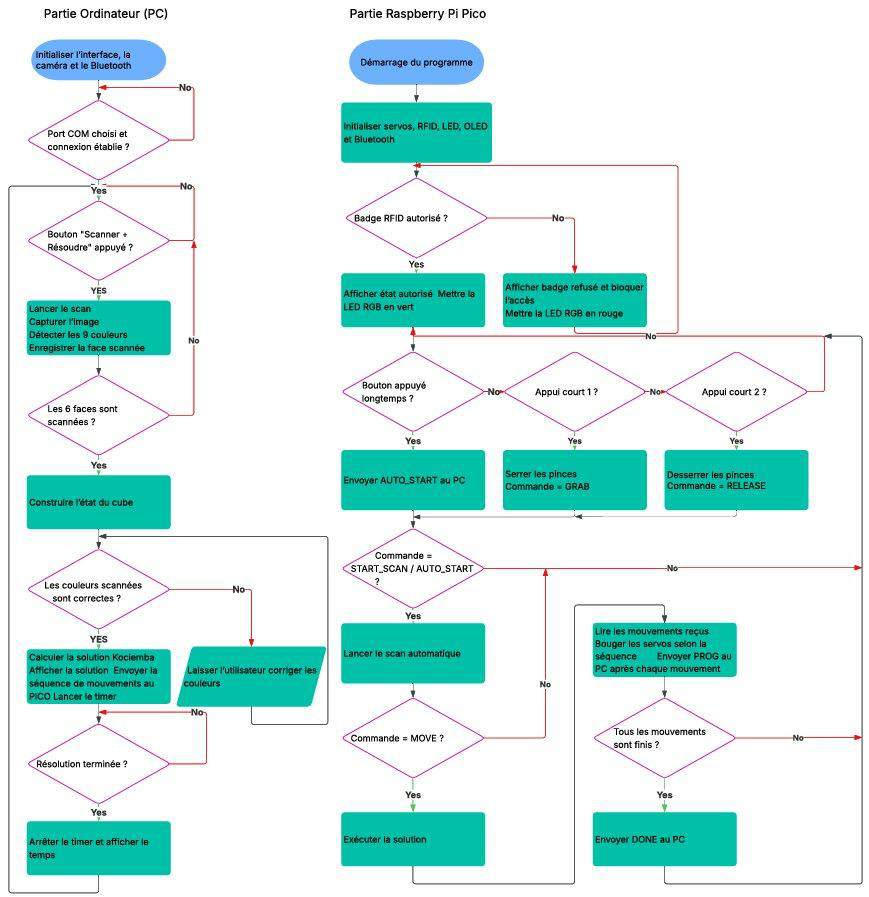
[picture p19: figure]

Algorithme général : PC (gauche) / Pico (droite)

APPLICATION PC — Python 3

- Interface graphique Tkinter (caméra, cube, chrono)
- Détection des couleurs par caméra (OpenCV / HSV)
- Calcul de la solution — algorithme Kociemba

FIRMWARE PICO — MicroPython

- Pilotage des 8 servomoteurs (4 bras)
- RFID, écran OLED, LED RGB, bouton
- Exécution séquentielle des mouvements

Liaison Bluetooth HC-05 · START:TAG:PAYLOAD:END

Rubik's Cube Solver — Groupe B02

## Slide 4

PARTIE ÉLECTRONIQUE

Les composants du système

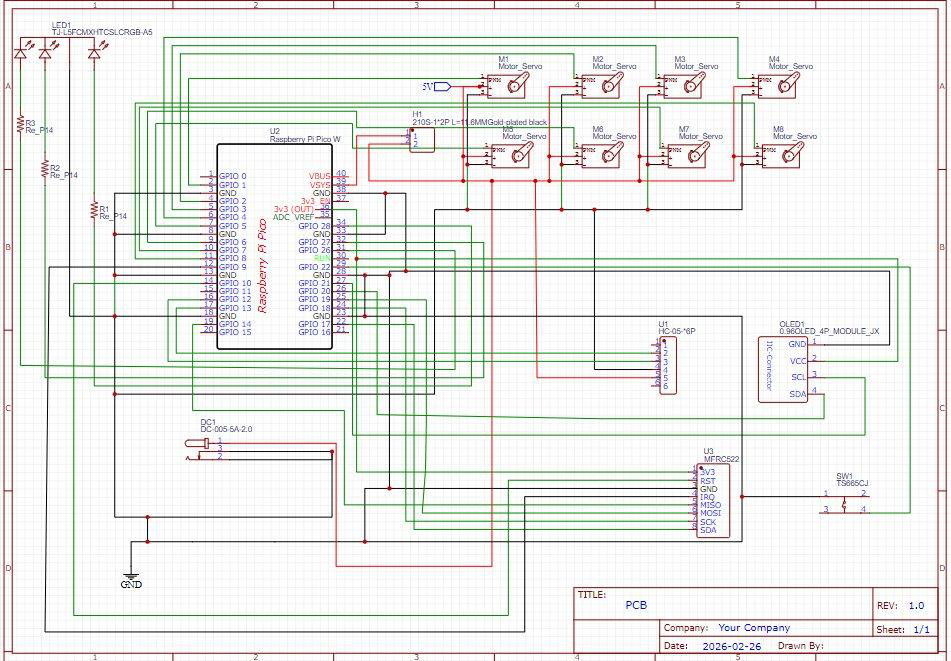
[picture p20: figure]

Schéma électrique complet

Alimentation 5 V séparée pour les servos : évite les chutes de tension lors des mouvements simultanés.

Raspberry Pi Pico W — Microcontrôleur — firmware MicroPython

HC-05 Bluetooth — Liaison PC ↔ Pico (UART, 38 400 bauds)

MFRC522 RFID — Identification par badge (SPI)

OLED SSD1306 — Affichage état & progression (I2C)

8× servos MG90S — 4 rotations + 4 pinces (PWM 50 Hz)

LED RGB + bouton — État visuel & commande manuelle

Rubik's Cube Solver — Groupe B02

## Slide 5

PARTIE ÉLECTRONIQUE

Un PCB conçu sur mesure

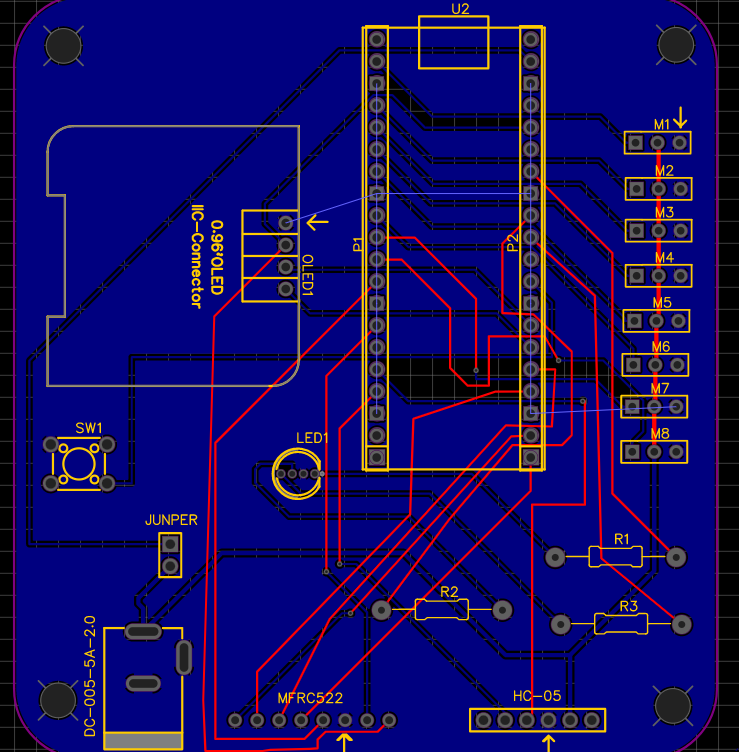
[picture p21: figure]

Routage

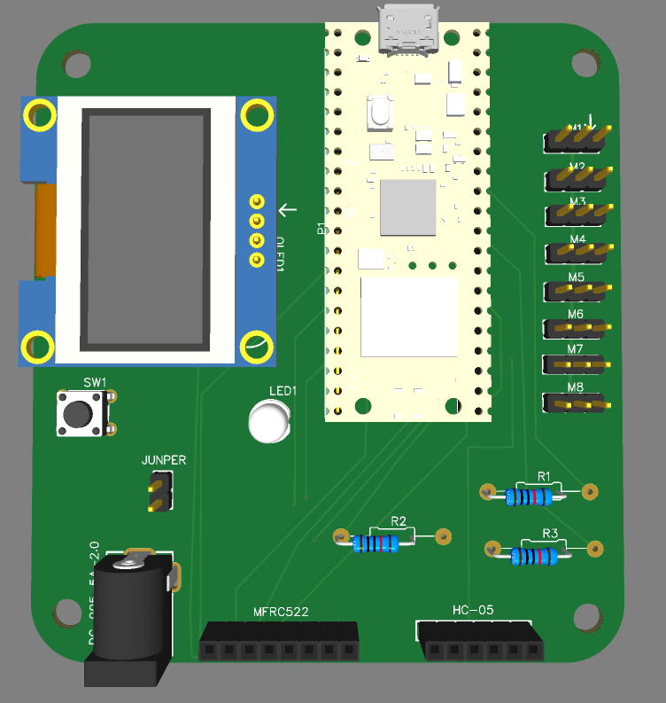
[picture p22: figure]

Rendu 3D

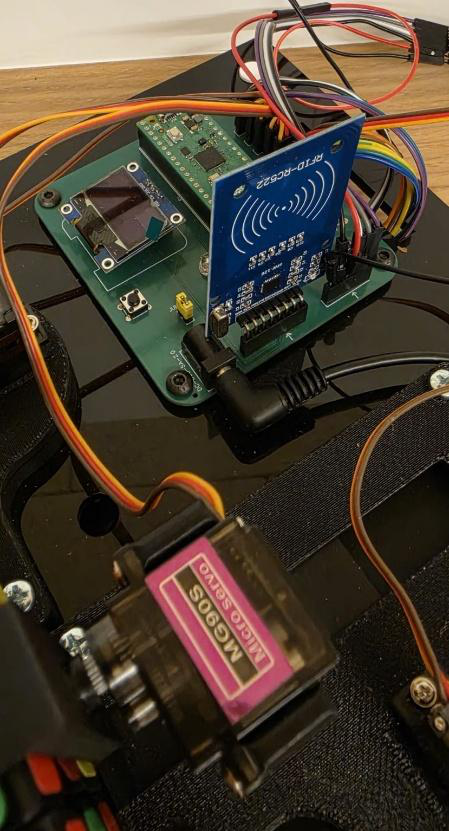
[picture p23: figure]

PCB soudé & assemblé

81,15 × 88,14 mm · 21 composants · 2 couches · 141 pastilles · fabriqué via JLCPCB

Rubik's Cube Solver — Groupe B02

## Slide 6

PARTIE MÉCANIQUE

Une structure en croix à 4 bras

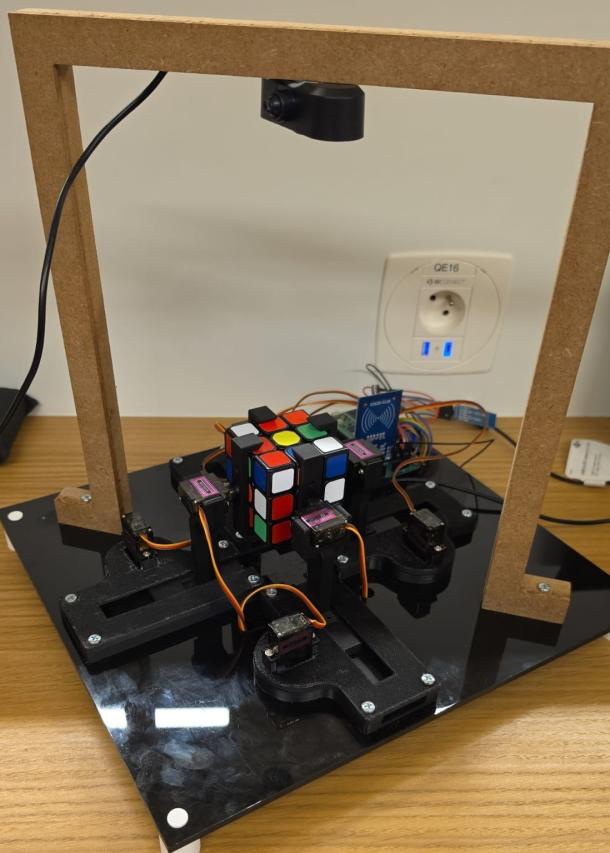
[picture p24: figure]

Robot assemblé

Rubik's Cube Solver — Groupe B02


Plan de découpe laser

Principe

- 4 bras en croix face aux faces F, B, L, R du cube
- Chaque bras = 1 servo de rotation + 1 servo de pince
- Base découpée au laser : positionnement précis et reproductible
- Pièces des bras imprimées en PLA (Fusion 360)
- Caméra USB fixée au-dessus du centre

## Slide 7

PARTIE MÉCANIQUE

Pièces modélisées sous Fusion 360


Platine support servo


Colonne verticale


Engrenage (trou en D)


Cadre structural en U

Rubik's Cube Solver — Groupe B02


Support de caméra


Pince de saisie

Tolérances ajustées (+0,2 mm) après plusieurs itérations d'impression.

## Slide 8

PARTIE MÉCANIQUE

Servomoteurs MG90S & calibrage par bras

Paramètre | Bras L | Bras R / F | Bras B
ROT_CENTER (neutre) | 86° | 90° | 94°
GRIP_HOLD (saisie) | 20° | 18° / 30° | 35°
GRIP_OPEN (relâche) | 100° | 100° | 100°
Temps / mouvement | 0,12 s | 0,12 s | 0,12 s

Chaque mouvement (R, U', F2…) → rotation CW/CCW → relâche pince → retour centre → saisie

Rubik's Cube Solver — Groupe B02

Pourquoi un calibrage individuel ?

- Chaque bras a ses propres constantes : compense les asymétries mécaniques de l'impression 3D
- Couple 1,8 kg/cm à 5 V — engrenages métal
- U et D (pas de bras dédié) : basculement du cube + rotation de la face accessible

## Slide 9

PROGRAMMATION — PICO

Firmware MicroPython : 8 modules

main.py Boucle principale : RFID, bouton, Bluetooth

Le bouton physique

- Appui court (< 0,8 s) : ouvrir / serrer les pinces
- Appui long (> 0,8 s) : scan automatique des 6 faces

servo_controller.py 4 bras / 8 servos, calibrage individuel

state.py Machine à états : IDLE / MOVING / SCAN

Sécurité RFID

- Liste blanche de badges autorisés
- Badge refusé → LED rouge, commandes bloquées, ERR:NOT_AUTHORIZED envoyé au PC

bluetooth.py UART 0, buffer 512 octets, parsing du protocole

rfid + oled + led Badge, affichage 4 lignes, LED RGB d'état

Rubik's Cube Solver — Groupe B02

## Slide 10

PROGRAMMATION — COMMUNICATION

Protocole Bluetooth maison

START : TAG : PAYLOAD : END\n

Direction | Tag | Rôle
PC → Pico | MOVE / GRAB / RELEASE | Exécuter une séquence, serrer / relâcher les pinces
PC → Pico | START_SCAN / SCAN_ACK | Déclencher le scan, acquitter chaque face capturée
Pico → PC | SCAN_READY / SCAN_DONE | Face en position devant la caméra, scan terminé
Pico → PC | PROG:i/total / DONE | Progression mouvement par mouvement
Pico → PC | AUTH:id,0|1 | Résultat de la lecture RFID

Buffer logiciel de 512 octets côté Pico : absorbe les longues solutions et filtre le bruit d'initialisation du HC-05.

Rubik's Cube Solver — Groupe B02

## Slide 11

PROGRAMMATION — PC

L'interface de supervision Tkinter


Rubik's Cube Solver — Groupe B02

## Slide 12

PROGRAMMATION — VISION

Détection des couleurs (OpenCV / HSV)

1

2

3

4

Patch 17×17 px par case du cube

Couleur médiane comparée aux plages HSV

| Couleur | Teinte H | Conditions
| Blanc | 0 – 180 | S < 60 et V > 170
| Orange | 6 – 22 | testé AVANT le rouge
| Jaune | 23 – 38 | S > 80 et V > 80
| Vert | 39 – 85 | S > 70 et V > 50
| Bleu | 95 – 135 | S > 70 et V > 50
| Rouge | 0-5 / 170-179 | double plage circulaire

Rubik's Cube Solver — Groupe B02

9 captures successives par face

Vote majoritaire case par case

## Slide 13

PROGRAMMATION — RÉSOLUTION

L'algorithme Kociemba

6 faces scannées

→

Chaîne de 54 caractères
(ordre U-R-F-D-L-B)

→

kociemba.solve()

→

Solution ≤ 20 mouvements
R U R' F2 …

- Algorithme « two-phase » de Herbert Kociemba — tables précalculées embarquées localement (dossier twophase/), aucun service externe
- La solution est envoyée au Pico via Bluetooth (MOVE:…) puis exécutée mouvement par mouvement
- Après chaque étape : PROG:i/total → barre de progression + simulation en direct sur le CubeView

Résolution physique complète : ≈ 20 secondes

Rubik's Cube Solver — Groupe B02

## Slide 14

RETOUR D'EXPÉRIENCE

Difficultés rencontrées & solutions

Précision des servos

Calibrage individuel par bras (ROT_CENTER, GRIP_HOLD)

Confusion orange / rouge

Orange testé avant le rouge + fallback par distance circulaire sur H

Détection couleur instable

Vote majoritaire sur 7 captures au lieu d'un seuil fixe

Bruit du HC-05 (« OK\r\n »)

Recherche du pattern START: dans le flux, buffer 512 octets

Rubik's Cube Solver — Groupe B02

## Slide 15

Conclusion

Objectif atteint — un robot 100 % autonome : scan → calcul → exécution en ≈ 20 s

Place à la démonstration !

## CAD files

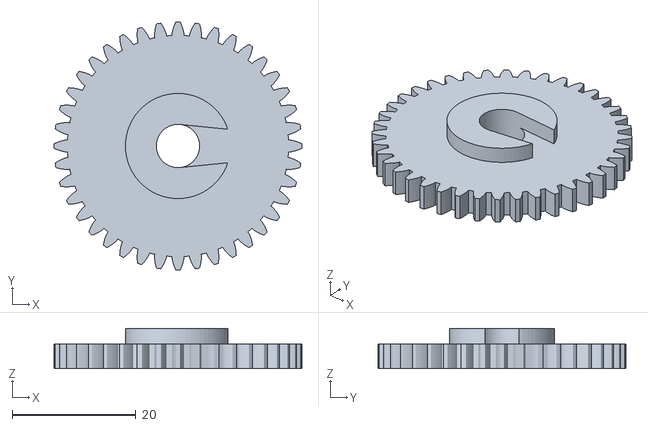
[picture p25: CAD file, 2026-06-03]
Partie mécanique/Engrenage de déplacement.stl
40.1 x 40.1 x 6.50

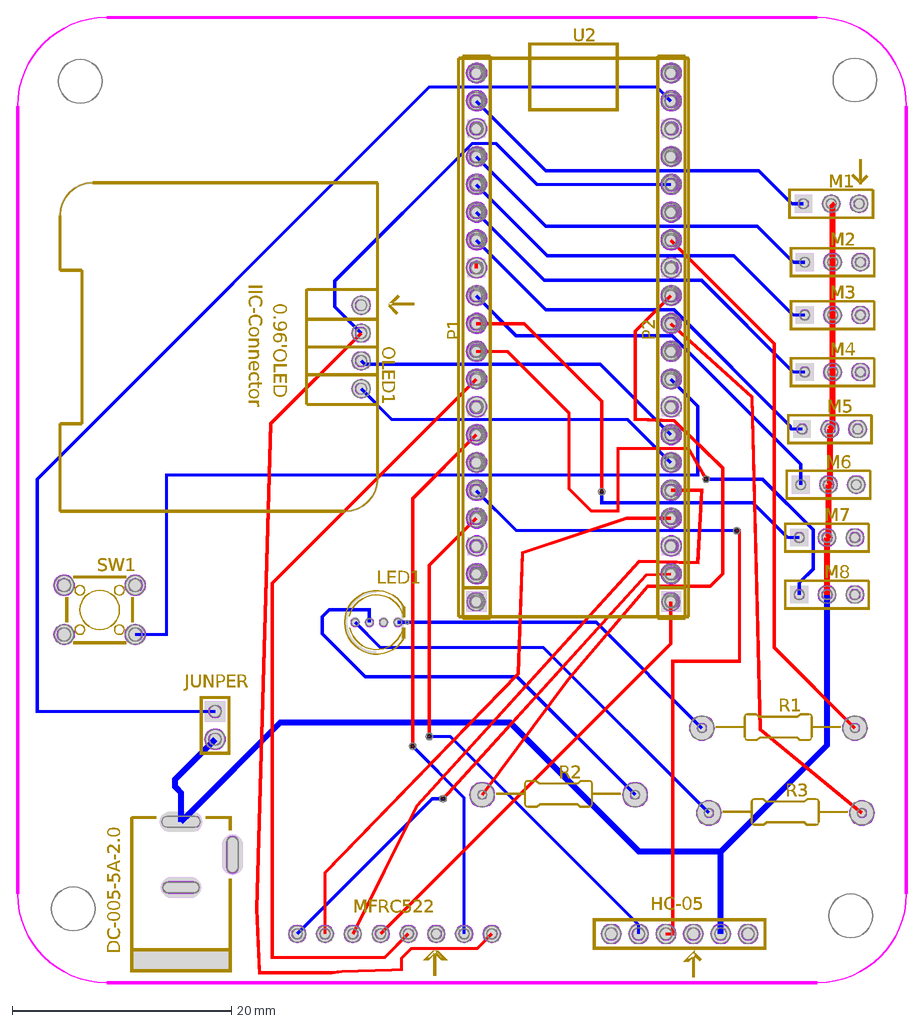
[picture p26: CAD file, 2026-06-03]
Partie électronique/PCB_PCB-Robotique_2_2026-06-03.dxf
DC-005-5A-2.0
LED1
M1
M2
M3
M4
M5
M6
M7
M8
OLED1
IIC-Connector
0.96'OLED
P1
P2
R1
R2
R3
SW1
HC-05
U2
MFRC522
JUNPER

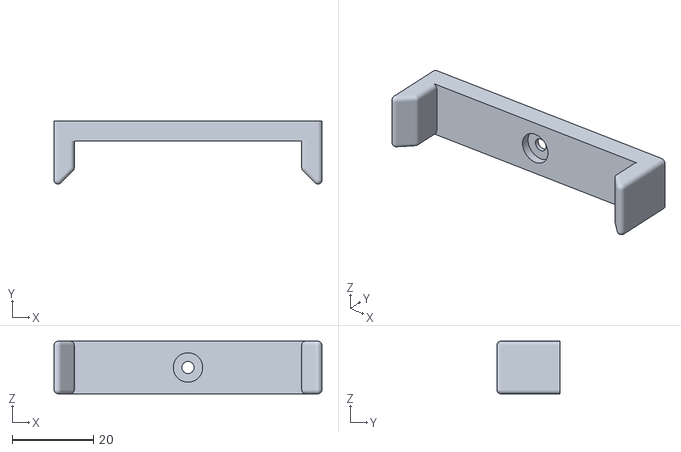
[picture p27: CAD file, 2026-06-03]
Partie mécanique/Pince.stl
66.1 x 15.6 x 13.0

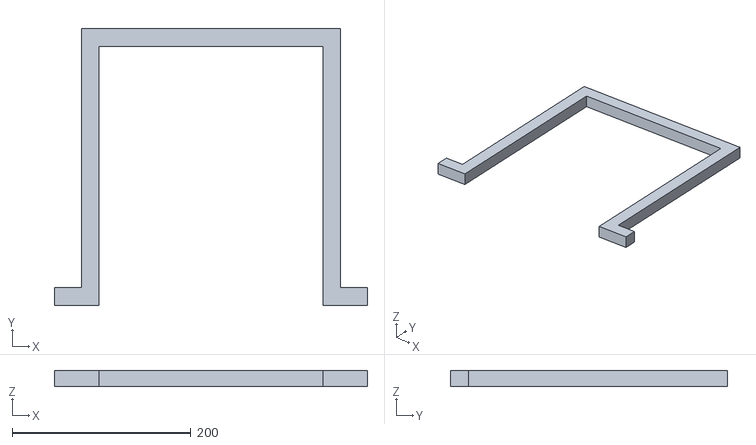
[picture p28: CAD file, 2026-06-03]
Partie mécanique/Support+caméra.stl
350.0 x 310.0 x 18.0

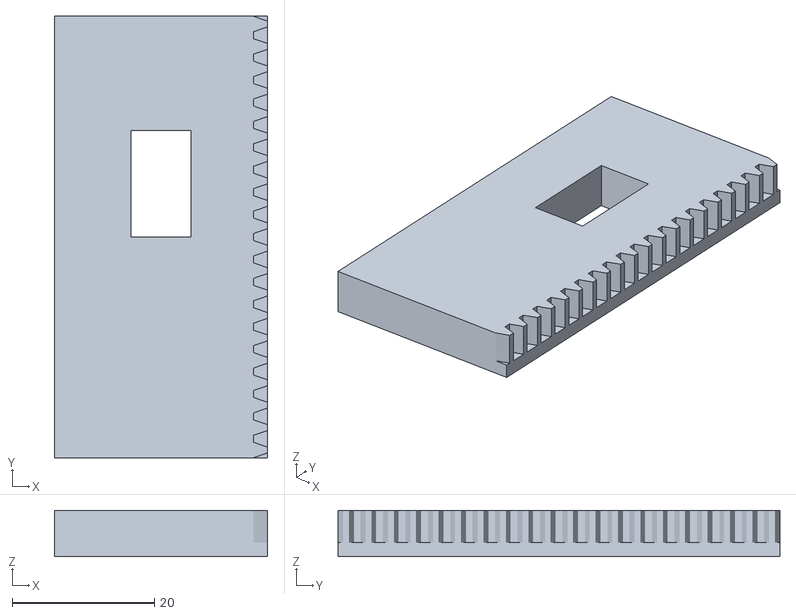
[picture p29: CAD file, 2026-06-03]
Partie mécanique/Support+du+déplacement.stl
30.0 x 62.2 x 6.50

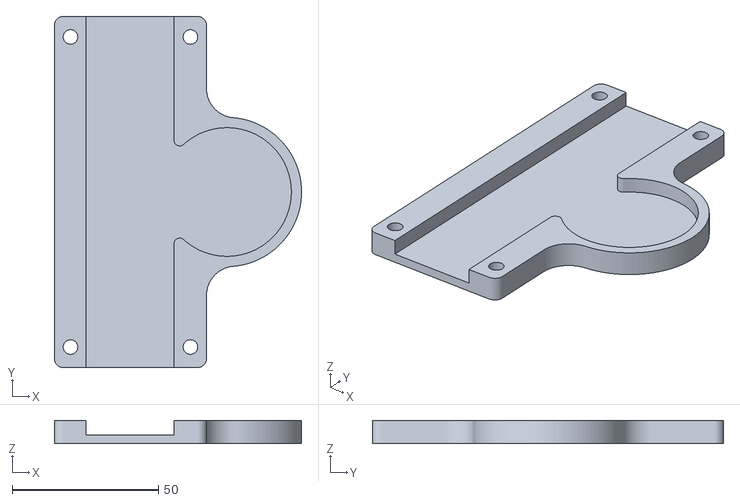
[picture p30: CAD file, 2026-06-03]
Partie mécanique/Support+principal.stl
84.5 x 120.0 x 8.00

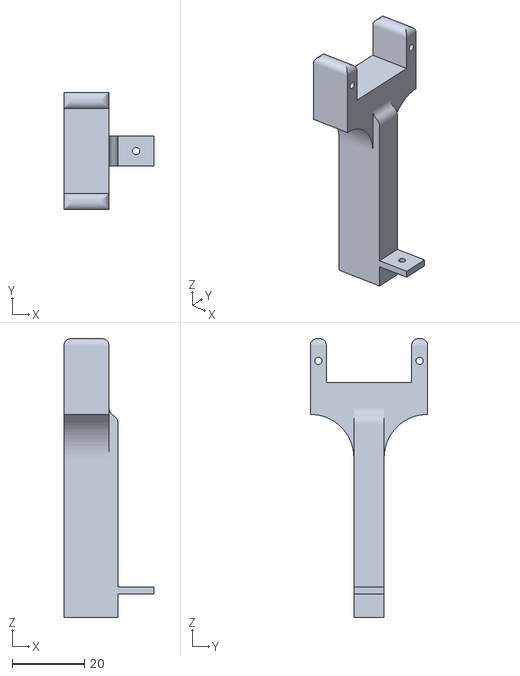
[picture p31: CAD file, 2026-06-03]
Partie mécanique/Support+servomoteur.stl
25.0 x 32.5 x 77.2

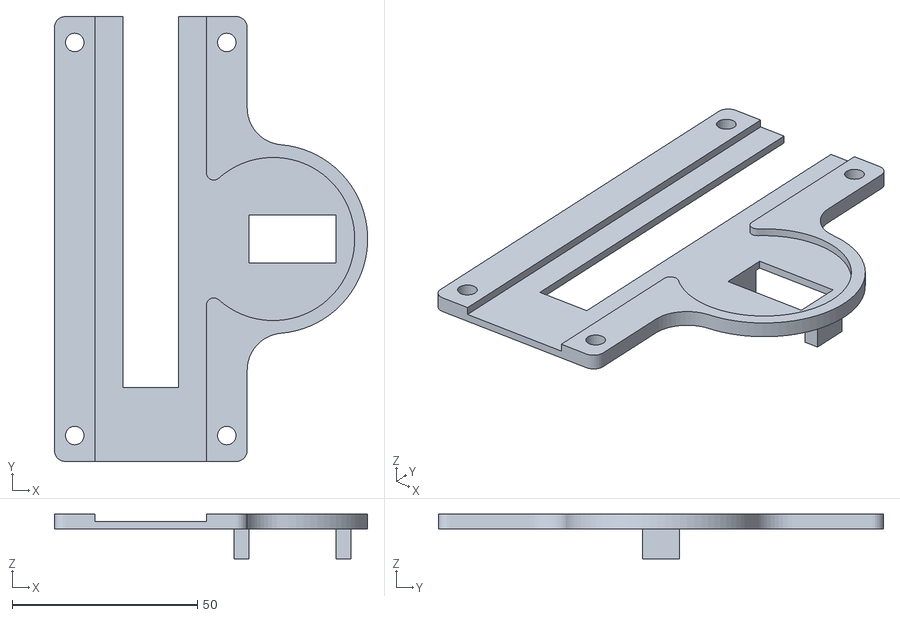
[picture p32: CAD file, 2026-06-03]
Partie mécanique/Support+principal+servomoteur.stl
84.5 x 120.0 x 12.0

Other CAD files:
Partie mécanique/Support Rubik's Cube solver.dwg

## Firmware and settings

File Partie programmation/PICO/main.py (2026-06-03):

from bluetooth import Bluetooth
from servo_controller import RobotController, TEMPS_SCAN
from led_controller import LEDController
from oled_display import OLED
from rfid_reader import RFIDReader
from machine import Pin
import utime

# communication Bluetooth avec le PC (HC-05)
bt    = Bluetooth(uart_id=0, baudrate=38400, tx_pin=12, rx_pin=13)
# controle des 4 bras du robot
robot = RobotController()
# LED RGB pour montrer l etat du robot
led   = LEDController(pins=(26,27,2))
# ecran OLED pour afficher les messages
oled  = OLED()
# lecteur de badge RFID
rfid  = RFIDReader(sck=18, mosi=19, miso=0, rst=10, cs=17)

# seul ce badge est autorise a utiliser le robot
ALLOWED_TAGS = [54206395]
rfid.set_allowed(ALLOWED_TAGS)

rfid_authorized = False
rfid_card_id    = None

# bouton physique sur le robot
btn_start = Pin(22, Pin.IN, Pin.PULL_UP)

_btn_last       = 1
_btn_press_time = 0
_grab_state     = False
# appui long = plus de 800ms = lancer le scan
LONG_PRESS_MS   = 800

_last_bt_ms   = 0
# si pas de message Bluetooth depuis 30s, on considere la connexion perdue
BT_TIMEOUT_MS = 30000


# rouge = pas de badge, vert = badge ok + BT actif
def led_etat():
    if not rfid_authorized:
        led.set(200, 0, 0)
    elif utime.ticks_diff(utime.ticks_ms(), _last_bt_ms) < BT_TIMEOUT_MS:
        led.set(0, 200, 0)
    else:
        led.set(200, 0, 0)


def _oled_attente_badge():
    oled.show("Scannez votre", "badge pour", "continuer...", "")


def log(msg):
    bt.send("LOG", msg)


# verifie si un badge est pose sur le lecteur
def handle_rfid():
    global rfid_authorized, rfid_card_id

    res = rfid.scan_once()
    if not res:
        return

    card, allowed = res
    rfid_card_id = card
    status = "1" if allowed else "0"
    # envoie l id et le resultat au PC
    bt.send("AUTH", "{},{}".format(card, status))

    card_str = str(card)
    # bleu pendant la lecture du badge
    led.set(0, 0, 200)

    if allowed:
        rfid_authorized = True
        oled.show("BIENVENU!", card_str[:8], "Autorise", "")
        log("RFID autorise: {}".format(card))
        utime.sleep_ms(1500)
        led_etat()
        oled.show("Robot pret", "Commandes OK", "", "")
    else:
        rfid_authorized = False
        oled.show("Badge refuse", card_str[:8], "Non autorise", "")
        log("RFID refuse: {}".format(card))
        # 3 clignotements rouges pour signaler le refus
        for _ in range(3):
            led.set(0, 0, 0)
            utime.sleep_ms(100)
            led.set(200, 0, 0)
            utime.sleep_ms(100)
        utime.sleep_ms(1000)
        _oled_attente_badge()


# bloque toute commande si pas de badge valide
def _bloquer(raison=""):
    log("BLOQUE badge requis" + (" (" + raison + ")" if raison else ""))
    led.set(200, 0, 0)
    oled.show("Scannez votre", "badge pour", "continuer...", "")
    bt.send("ERR", "NOT_AUTHORIZED")


# ferme les 4 pinces (attrape le cube)
def _do_grab():
    global _grab_state
    if not rfid_authorized:
        _bloquer("GRAB bouton")
        return
    _grab_state = True
    robot.tout_serrer()
    bt.send("OK", "GRAB")
    oled.show("Pinces", "Serrees", "", "")
    led.set(200, 100, 0)
    utime.sleep_ms(300)
    led_etat()


# ouvre les 4 pinces (lache le cube)
def _do_release():
    global _grab_state
    if not rfid_authorized:
        _bloquer("RELEASE bouton")
        return
    _grab_state = False
    robot.tout_lacher()
    bt.send("OK", "RELEASE")
    oled.show("Pinces", "Lachees", "", "")
    led_etat()


# gere l appui sur le bouton physique
def check_button():
    global _btn_last, _btn_press_time

    val = btn_start.value()

    if _btn_last == 1 and val == 0:
        _btn_press_time = utime.ticks_ms()

    elif _btn_last == 0 and val == 1:
        duration = utime.ticks_diff(utime.ticks_ms(), _btn_press_time)

        if duration >= LONG_PRESS_MS:
            if not rfid_authorized:
                _bloquer("bouton long")
                return
            # appui long = demarre le scan automatique
            bt.send("AUTO_START", "")
            oled.show("Demarrage", "Scan auto...", "", "")
            led.set(0, 150, 200)
        else:
            # appui court = ouvre/ferme les pinces
            if _grab_state:
                _do_release()
            else:
                _do_grab()

    _btn_last = val


# attend que le PC confirme la capture d une face (SCAN_ACK)
def wait_ack(face_name, timeout_ms=60000):
    t0 = utime.ticks_ms()
    while utime.ticks_diff(utime.ticks_ms(), t0) < timeout_ms:
        line = bt.readline()
        tag, payload = bt.parse(line)
        if tag == "SCAN_ACK" and payload == face_name:
            return True
        utime.sleep_ms(50)
    return False


# place le cube pour scanner une face, puis attend la confirmation du PC
def expose_and_capture(face_name, step_num):
    oled.show("Scan {}/6".format(step_num), "Face " + face_name, "", "")
    utime.sleep_ms(1000)
    bt.send("SCAN_READY", face_name)

    if not wait_ack(face_name):
        oled.show("ERREUR", "Timeout " + face_name, "", "")
        bt.send("ERR", "SCAN_TIMEOUT_" + face_name)
        return False

    led.set(0, 200, 0)
    utime.sleep_ms(200)
    led.set(0, 150, 200)
    return True


# sequence complete de scan des 6 faces : U R F D L B
def auto_scan():
    led.set(0, 150, 200)
    oled.show("Scan auto", "Debut...", "", "")
    S = TEMPS_SCAN
    W = 1500

    # face U : position initiale (blanc en haut)
    robot.position_scan(S); utime.sleep_ms(W)
    if not expose_and_capture("U", 1):
        robot.fin_scan(S); led_etat(); return False
    robot.fin_scan(S); utime.sleep_ms(W)

    # aller vers face verte pour servir de reference
    robot.basculer_arriere(S); utime.sleep_ms(W)

    # face R : depuis vert, tourner vers rouge
    robot.basculer_gauche(S); utime.sleep_ms(W)
    robot.position_scan(S);   utime.sleep_ms(W)
    if not expose_and_capture("R", 2):
        robot.fin_scan(S); led_etat(); return False
    robot.fin_scan(S); utime.sleep_ms(W)

    # retour face verte
    robot.basculer_droite(S); utime.sleep_ms(W)

    # face F : vert deja en haut
    robot.position_scan(S); utime.sleep_ms(W)
    if not expose_and_capture("F", 3):
        robot.fin_scan(S); led_etat(); return False
    robot.fin_scan(S); utime.sleep_ms(W)

    # face D : descendre vers jaune
    robot.basculer_arriere(S); utime.sleep_ms(W)
    robot.position_scan(S);    utime.sleep_ms(W)
    if not expose_and_capture("D", 4):
        robot.fin_scan(S); led_etat(); return False
    robot.fin_scan(S); utime.sleep_ms(W)

    # retour face verte
    robot.basculer_avant(S); utime.sleep_ms(W)

    # face L : depuis vert, tourner vers orange
    robot.basculer_droite(S); utime.sleep_ms(W)
    robot.position_scan(S);   utime.sleep_ms(W)
    if not expose_and_capture("L", 5):
        robot.fin_scan(S); led_etat(); return False
    robot.fin_scan(S); utime.sleep_ms(W)

    # face B : depuis orange, tourner vers bleu
    robot.basculer_droite(S); utime.sleep_ms(W)
    robot.position_scan(S);   utime.sleep_ms(W)
    if not expose_and_capture("B", 6):
        robot.fin_scan(S); led_etat(); return False
    robot.fin_scan(S); utime.sleep_ms(W)

    # retour position initiale (blanc en haut)
    robot.basculer_gauche(S); utime.sleep_ms(W)
    robot.basculer_gauche(S); utime.sleep_ms(W)
    robot.basculer_avant(S);  utime.sleep_ms(W)

    oled.show("Scan OK!", "6/6 faces", "", "")
    bt.send("SCAN_DONE", "OK")
    led.set(0, 200, 0)
    utime.sleep_ms(1000)
    led_etat()
    return True


# execute la liste de mouvements envoyes par le PC (algorithme Kociemba)
def execute_moves(payload):
    led.set(200, 100, 0)
    moves = payload.split()
    total = len(moves)

    for i, mvt in enumerate(moves, 1):
        oled.show("Move {}/{}".format(i, total), mvt, "", "")
        robot.executer_mouvement_rubiks(mvt)
        # envoie la progression au PC pour mettre a jour l interface
        bt.send("PROG", "{}/{}".format(i, total))

    bt.send("DONE", "MOVE")
    led.set(0, 200, 0)
    oled.show("Felicitations!", "Resolu!", str(total) + " moves", "")
    utime.sleep_ms(3000)
    led_etat()
    oled.show("Robot pret", "Commandes OK", "", "")


# initialisation du robot au demarrage
robot.initialiser()
led.set(200, 0, 0)
_oled_attente_badge()
bt.send("LOG", "PICO_READY")

last_rfid = 0

# boucle principale : ecoute Bluetooth + verifie badge + verifie bouton
while True:
    now = utime.ticks_ms()

    # scan RFID toutes les 500ms
    if utime.ticks_diff(now, last_rfid) > 500:
        handle_rfid()
        last_rfid = utime.ticks_ms()

    check_button()

    line = bt.readline()
    tag, payload = bt.parse(line)

    if tag is None:
        utime.sleep_ms(20)
        continue

    # une commande recue = Bluetooth toujours actif
    _last_bt_ms = utime.ticks_ms()

    if tag == "PING":
        bt.send("PONG")
        led_etat()

    elif tag == "SCAN":
        handle_rfid()

    elif not rfid_authorized:
        _bloquer(tag)

    elif tag == "MOVE":
        execute_moves(payload)

    elif tag == "GRAB":
        _do_grab()

    elif tag == "RELEASE":
        _do_release()

    elif tag == "START_SCAN":
        auto_scan()

    elif tag == "AUTO_START":
        auto_scan()

    utime.sleep_ms(20)

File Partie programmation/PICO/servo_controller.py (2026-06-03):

from machine import Pin, PWM
import time

# position neutre calibree pour chaque bras (centre du servo)
ROT_CENTER = {"L": 86, "R": 90, "F": 90, "B": 94}
# amplitude de rotation depuis le centre (centre+step = position max)
ROT_STEP   = {"L": 90, "R": 90, "F": 90, "B": 90}
ROT_SIGN   = {"L": 1,  "R": 1,  "F": 1,  "B": 1}

# angle de serrage de la pince
GRIP_HOLD  = {"L": 20, "R": 18, "F": 30, "B": 35}
# angle d ouverture de la pince
GRIP_OPEN  = {"L": 100, "R": 100, "F": 100, "B": 100}
GRIP_BACK  = {"L": 100, "R": 100, "F": 100, "B": 100}

# delai entre chaque mouvement pendant la resolution
TEMPS_MVT  = 0.12
# delai pendant le scan (plus lent pour pas lacher le cube)
TEMPS_SCAN = 0.30


class Bras:
    def __init__(self, nom, pin_rot, pin_pince):
        self.nom = nom
        # servo de rotation du bras
        self.rot   = PWM(Pin(pin_rot));   self.rot.freq(50)
        # servo de la pince
        self.pince = PWM(Pin(pin_pince)); self.pince.freq(50)
        self.center   = ROT_CENTER[nom]
        self.step     = ROT_STEP[nom]
        self.sign     = ROT_SIGN[nom]
        self.hold_ang = GRIP_HOLD[nom]
        self.open_ang = GRIP_OPEN[nom]
        self.back_ang = GRIP_BACK[nom]

    # convertit un angle en signal PWM pour le servo de rotation
    def _angle_rot(self, pwm, angle):
        duty = int(1638 + (8192 - 1638) * (angle / 180.0))
        pwm.duty_u16(min(max(duty, 0), 65535))

    # convertit un angle en signal PWM pour la pince
    def _angle_grip(self, pwm, angle):
        duty = int(1638 + (8192 - 1638) * (angle / 180.0))
        pwm.duty_u16(min(max(duty, 0), 65535))

    def serrer(self):
        self._angle_grip(self.pince, self.hold_ang)

    def lacher(self):
        self._angle_grip(self.pince, self.open_ang)

    def recul(self):
        self._angle_grip(self.pince, self.back_ang)

    # revient a la position neutre
    def rot_centre(self):
        self._angle_rot(self.rot, self.center)

    # tourne dans le sens horaire
    def rot_cw(self):
        angle = max(0, min(180, self.center + self.step * self.sign))
        self._angle_rot(self.rot, angle)

    # tourne dans le sens anti-horaire
    def rot_ccw(self):
        angle = max(0, min(180, self.center - self.step * self.sign))
        self._angle_rot(self.rot, angle)


class RobotController:
    def __init__(self):
        # creation des 4 bras : Front, Back, Right, Left
        self.F = Bras("F", pin_rot=5, pin_pince=6)
        self.B = Bras("B", pin_rot=1, pin_pince=2)
        self.R = Bras("R", pin_rot=3, pin_pince=4)
        self.L = Bras("L", pin_rot=7, pin_pince=8)
        self.bras = {'F': self.F, 'B': self.B, 'R': self.R, 'L': self.L}

    # au demarrage : centre tous les bras puis serre
    def initialiser(self):
        for b in self.bras.values():
            b.rot_centre()
            b.lacher()
        time.sleep(1)
        for b in self.bras.values():
            b.serrer()
        time.sleep(0.5)

    def tout_serrer(self):
        for b in self.bras.values():
            b.serrer()

    # position pour scanner une face : L et R tiennent, F et B s ecartent
    def position_scan(self, d=TEMPS_MVT):
        self.L.lacher()
        self.R.lacher()
        time.sleep(d)
        self.L.rot_cw()
        self.R.rot_cw()
        time.sleep(d)
        self.L.serrer()
        self.R.serrer()
        time.sleep(d)
        self.F.lacher()
        self.B.lacher()
        time.sleep(d)
        self.F.rot_cw()
        self.B.rot_cw()
        time.sleep(d)

    # apres le scan : remet les 4 bras en position normale
    def fin_scan(self, d=TEMPS_MVT):
        self.F.rot_centre()
        self.B.rot_centre()
        time.sleep(d)
        self.F.serrer()
        self.B.serrer()
        time.sleep(d)
        self.L.lacher()
        self.R.lacher()
        time.sleep(d)
        self.L.rot_centre()
        self.R.rot_centre()
        time.sleep(d)
        self.L.serrer()
        self.R.serrer()
        time.sleep(d)

    def tout_lacher(self):
        for b in self.bras.values():
            b.lacher()

    # tourne une face du cube (CW = sens horaire, CCW = anti-horaire, 2 = 180 degres)
    def _tourner(self, face, direction):
        b = self.bras[face]
        if direction == "2":
            self._tourner(face, "CW")
            self._tourner(face, "CW")
            return
        b.rot_cw() if direction == "CW" else b.rot_ccw()
        time.sleep(TEMPS_MVT)
        b.lacher()
        time.sleep(TEMPS_MVT)
        b.rot_centre()
        time.sleep(TEMPS_MVT)
        b.serrer()
        time.sleep(TEMPS_MVT)

    # bascule le cube vers l avant (L et R font pivoter)
    def basculer_avant(self, d=TEMPS_MVT):
        self.F.lacher();  self.B.lacher();  time.sleep(d)
        self.L.rot_cw();  self.R.rot_ccw(); time.sleep(d)
        self.F.serrer();  self.B.serrer();  time.sleep(d)
        self.L.lacher();  self.R.lacher();  time.sleep(d)
        self.L.rot_centre(); self.R.rot_centre(); time.sleep(d)
        self.L.serrer();  self.R.serrer();  time.sleep(d)

    # bascule le cube vers l arriere
    def basculer_arriere(self, d=TEMPS_MVT):
        self.F.lacher();  self.B.lacher();  time.sleep(d)
        self.L.rot_ccw(); self.R.rot_cw();  time.sleep(d)
        self.F.serrer();  self.B.serrer();  time.sleep(d)
        self.L.lacher();  self.R.lacher();  time.sleep(d)
        self.L.rot_centre(); self.R.rot_centre(); time.sleep(d)
        self.L.serrer();  self.R.serrer();  time.sleep(d)

    # bascule le cube vers la droite (F et B font pivoter)
    def basculer_droite(self, d=TEMPS_MVT):
        self.L.lacher();  self.R.lacher();  time.sleep(d)
        self.F.rot_cw();  self.B.rot_ccw(); time.sleep(d)
        self.L.serrer();  self.R.serrer();  time.sleep(d)
        self.F.lacher();  self.B.lacher();  time.sleep(d)
        self.F.rot_centre(); self.B.rot_centre(); time.sleep(d)
        self.F.serrer();  self.B.serrer();  time.sleep(d)

    # bascule le cube vers la gauche
    def basculer_gauche(self, d=TEMPS_MVT):
        self.L.lacher();  self.R.lacher();  time.sleep(d)
        self.F.rot_ccw(); self.B.rot_cw();  time.sleep(d)
        self.L.serrer();  self.R.serrer();  time.sleep(d)
        self.F.lacher();  self.B.lacher();  time.sleep(d)
        self.F.rot_centre(); self.B.rot_centre(); time.sleep(d)
        self.F.serrer();  self.B.serrer();  time.sleep(d)

    # execute un mouvement Kociemba (ex: R, L', F2, U, D')
    def executer_mouvement_rubiks(self, commande):
        face = commande[0]
        direction = "CW"
        if len(commande) > 1:
            if commande[1] == "'": direction = "CCW"
            elif commande[1] == "2": direction = "2"
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

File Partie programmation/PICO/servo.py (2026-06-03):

# classe generique pour controler un servomoteur via PWM sur le Pico
# un servomoteur recoit un signal PWM a 50Hz, la largeur d impulsion definit l angle

from machine import Pin, PWM

class Servo:
    # frequence du signal PWM : 50Hz = periode de 20ms (standard pour les servos)
    __servo_pwm_freq = 50
    # valeur minimale du rapport cyclique (correspond a 0 degres)
    __min_u16_duty = 1802
    # valeur maximale du rapport cyclique (correspond a 180 degres)
    __max_u16_duty = 7864
    min_angle = 0
    max_angle = 180
    current_angle = 0.001

    def __init__(self, pin):
        self.__initialise(pin)

    # permet de recalibrer le servo avec des valeurs differentes
    def update_settings(self, servo_pwm_freq, min_u16_duty, max_u16_duty, min_angle, max_angle, pin):
        self.__servo_pwm_freq = servo_pwm_freq
        self.__min_u16_duty = min_u16_duty
        self.__max_u16_duty = max_u16_duty
        self.min_angle = min_angle
        self.max_angle = max_angle
        self.__initialise(pin)

    # deplace le servo a l angle demande (en degres)
    def move(self, angle):
        # arrondit pour eviter des micro-corrections inutiles
        angle = round(angle, 2)
        # ne bouge pas si on est deja a cet angle
        if angle == self.current_angle:
            return
        self.current_angle = angle
        # convertit l angle en signal PWM et l envoie au servo
        duty_u16 = self.__angle_to_u16_duty(angle)
        self.__motor.duty_u16(duty_u16)

    # arrete le signal PWM (servo se relache)
    def stop(self):
        self.__motor.deinit()

    def get_current_angle(self):
        return self.current_angle

    # formule de conversion : angle -> valeur du rapport cyclique (16 bits)
    def __angle_to_u16_duty(self, angle):
        return int((angle - self.min_angle) * self.__angle_conversion_factor) + self.__min_u16_duty

    # initialise le PWM sur la broche et calcule le facteur de conversion
    def __initialise(self, pin):
        self.current_angle = -0.001
        # facteur = plage de duty / plage d angles
        self.__angle_conversion_factor = (self.__max_u16_duty - self.__min_u16_duty) / (self.max_angle - self.min_angle)
        self.__motor = PWM(Pin(pin))
        self.__motor.freq(self.__servo_pwm_freq)

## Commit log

2026-03-02 Initialisation du projet robot Rubik’s Cube
2026-03-09 Mise en place de l'architecture de base du projet
2026-04-03 test communication bluetooth pico et pc
2026-04-19 connexion BT + interface de base
2026-04-20 Visualisation cube 6 faces + camera live
2026-04-24 solver kociemba, solution, camera auto, timer automatique
2026-05-15 Ajout de l'affichage OLED pour les informations du robot
2026-05-15 Ajout de la lecture RFID
2026-06-02 Interface principale de pilotage du cube
2026-06-02 Scan des faces et préparation de la solution
2026-06-02 Ecran d’accueil et finition de l’interface
2026-06-03 Ajout des fichiers du solveur Rubik's Cube
2026-06-03 Ajout de commentaires
2026-06-03 Importation sélective des contrôleurs, main et state depuis la branche Elhamayda-_Amer
2026-06-03 organisation finale structure depot projet
    [Engrenage de déplacement.stl, PCB_PCB-Robotique_2_2026-06-03.dxf, Pince.stl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]
2026-06-10 Ajout de la présentation PowerPoint
